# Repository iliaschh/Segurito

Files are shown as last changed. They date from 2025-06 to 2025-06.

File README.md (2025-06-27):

# Segurito 

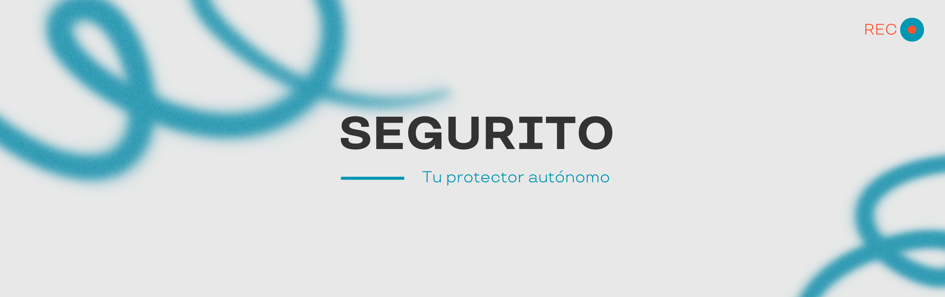
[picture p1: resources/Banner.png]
Logo del Proyecto


## Tabla de Contenidos

1. [Introducción](#introducción)
2. [Componentes y Costos](#componentes-y-costos)
3. [Características](#características)
4. [Modelo 3D](#modelo-3d)
5. [Diagramas de Arquitectura](#diagramas-de-arquitectura)
   - [Diagrama de Hardware](#diagrama-de-hardware)
   - [Diagrama de Software](#diagrama-de-software)
6. [Instalación](#instalación)
   - [Requisitos](#requisitos)
   - [Guía de Instalación](#guía-de-instalación)
7. [Uso](#uso)
   - [Escaneo y Mapeo LiDAR](#escaneo-y-mapeo-lidar)
   - [Detección de Movimiento](#detección-de-movimiento)
   - [Reconocimiento de Objetos y Rostros](#reconocimiento-de-objetos-y-rostros)
   - [Monitoreo Remoto](#monitoreo-remoto)
8. [Algoritmos](#algoritmos)
9. [Video funcionamiento](#Video-funcionamiento)
10. [Contribuidores](#contribuidores)
11. [Licencia](#licencia)

---

## Introducción

Segurito es un robot de seguridad autónomo diseñado para patrullar y supervisar espacios como lo haría un vigilante dedicado. Equipado con sensores avanzados y conectividad en la nube, Segurito:

- Mapea su entorno usando algoritmos LiDAR y SLAM
- Detecta obstáculos y objetos en movimiento para una navegación segura
- Identifica humanos y animales mediante reconocimiento por cámara
- Activa alarmas y envía notificaciones remotas al detectar intrusos
- Envia y recibe audios de voz en remoto a traves del altavoz y del micrófono integrado

Segurito combina hardware con módulos de software inteligentes para dar una solución de seguridad integral.

---

## Características

- **Mapeo Autónomo**: Genera un mapa en tiempo real del entorno usando LiDAR y SLAM.
- **Evitación de Colisiones**: Detecta y evita obstáculos.
- **Detección de Movimiento**: Sensor PIR para mayor precisión.
- **Reconocimiento de Humanos y Animales**: Clasifica las figuras capturadas por la cámara.
- **Sistema de Alarma**: Emite sonidos a traves del altavoz al detectar intrusos y enviar notificaciones.
- **Comandos de Voz**: Micrófono para hablar.
- **Conectividad en la Nube**: Envía alertas y transmisión de video en vivo a un panel remoto.

---

## Componentes y Costos

| Componente | Cantidad | Costo Aprox. (USD) | Enlace al Proveedor |
|---|:---:|---:|---|
| Micro Metal Motors | 2 | 35.00  | [Enlace](https://tienda.bricogeek.com/motores/113-motor-micro-metal-lp-con-reductora-10-1.html) |
| Raspberry Pi 4B (4 GB RAM)  | 1 | 67.90  | [Enlace](https://tienda.bricogeek.com/placas-raspberry-pi/1330-raspberry-pi-4-model-b-4-gb.html) |
| Sensor de Movimiento PIR | 1 | 1.85 | [Enlace](https://tienda.bricogeek.com/sensores-distancia/1270-modulo-sensor-pir-hc-sr501.html) |
| RPLIDAR-C1 | 1 | 79.95  | [Enlace](https://tienda.bricogeek.com/sensores-distancia/1943-rplidar-c1-360-grados-12-metros-ip54.html) |
| Acelerometro y Giroscopio | 1 | 2.95 | [Enlace](https://tienda.bricogeek.com/acelerometros/1682-modulo-gy-521-acelerometro-y-giroscopio-mpu-6050.html) |
| Ruedas Solarbotic | 2 | 9.80 | [Enlace](https://tienda.bricogeek.com/ruedas-robotica/1008-rueda-solarbotics-rw2i.html) |
| Rueda Loca | 1 | 5.50 | [Enlace](https://tienda.bricogeek.com/robotica/995-rueda-loca-plastico-abs-34.html) |
| Altavoz | 1 | 5.50 | [Enlace](https://tienda.bricogeek.com/varios/938-altavoz-con-caja-3w.html) |
| Controladores de Motor | 1 | 5.95 | [Enlace](https://tienda.bricogeek.com/controladores-motores/999-controlador-de-motores-tb6612fng.html) |
| Microfono | 1 | 7.30 | [Enlace](https://tienda.bricogeek.com/sensores-sonido/1475-microfono-digital-mems-i2s-sph0645.html) |
| Controladora de Microfono | 1 | 6.50 | [Enlace](https://tienda.bricogeek.com/arduino-compatibles/1274-nodemcu-esp32-wroom-wifi-bluetooth.html) |
| Camara | 1 | 19.95  | [Enlace](https://tienda.bricogeek.com/accesorios-raspberry-pi/822-camara-raspberry-pi-v2-8-megapixels.html) |
| Encoders de Motor | 2 | 8.50 | [Enlace](https://tienda.bricogeek.com/accesorios-motores/932-encoders-para-motores-micro-metal-12cpr.html) |
| Powerbank y Bateria | 2 | 10.00  | — |
| Breadboard y Cables | 1 | 0.00 | — |
| Chasis Impreso en 3D | 1 | 4.00 | — |
| **Total** | | **270.60**| |

---

## Modelo 3D

El chasis completo del robot y los soportes de los componentes han sido diseñados en OnShape. Puedes encontrar los archivos del modelo aquí:

- `3Dmodels/Base.stl`
- `3Dmodels/Adaptador Base.stl`
- `3Dmodels/Segundo Piso.stl`
- `3Dmodels/Adaptador Sensor PIR.stl`
- `3Dmodels/Adaptador Lidar.stl`
- `3Dmodels/Cupula.stl`

Vista Previa del Ensamblaje 3D

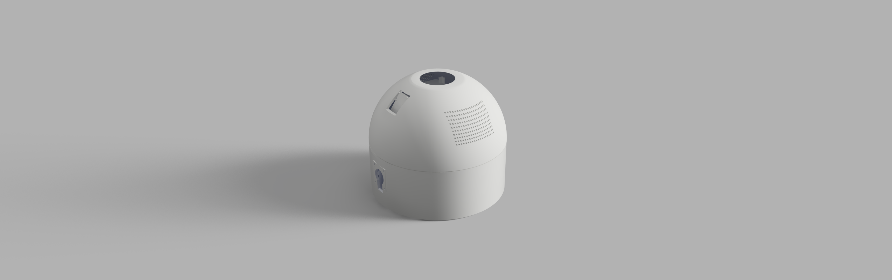
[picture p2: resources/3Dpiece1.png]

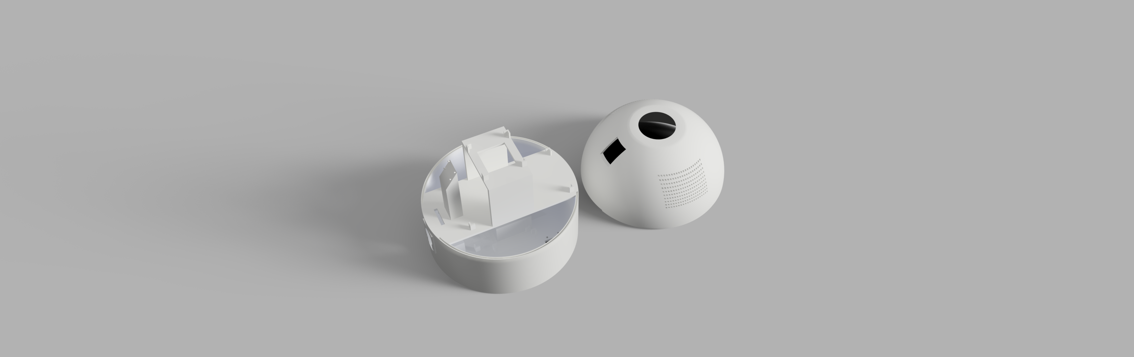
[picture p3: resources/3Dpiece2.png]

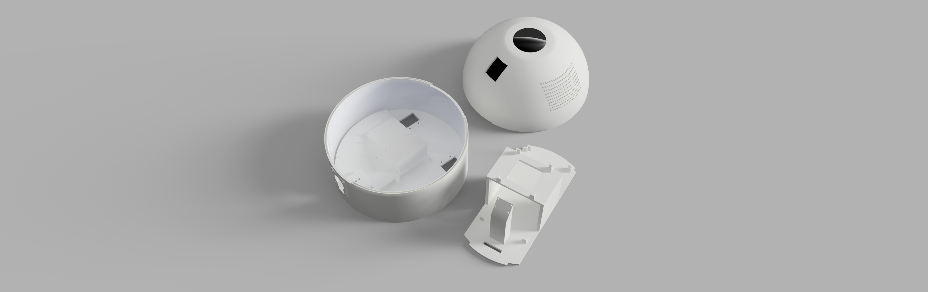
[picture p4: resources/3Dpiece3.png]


---

## Diagramas de Arquitectura

### Diagrama de Hardware

El circuito ha sido creado mediante la herramienta Fritzing, puedes encontrar el archivo aquí:

- `circuits/EsquemaCircuitos.fzz`

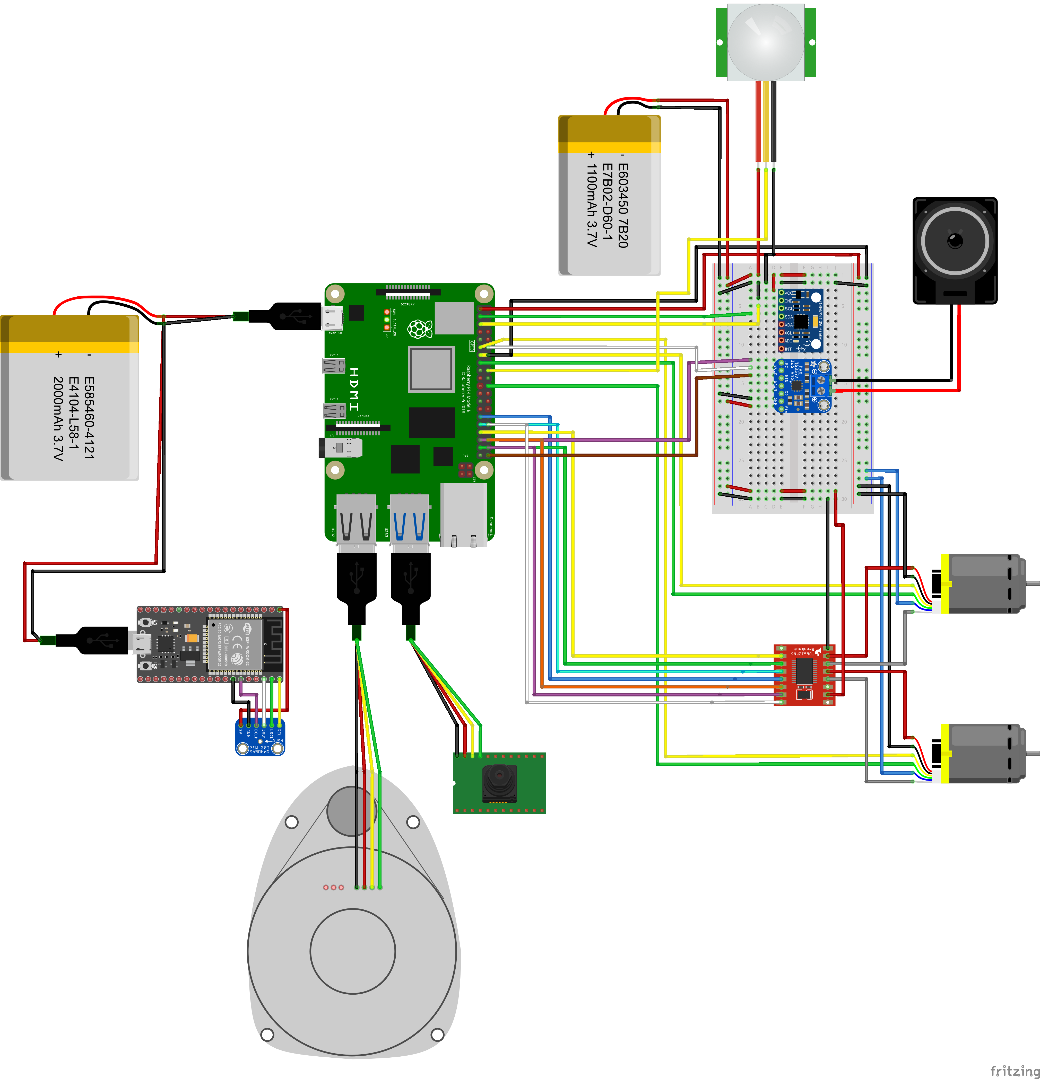
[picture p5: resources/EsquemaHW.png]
Diagrama de Hardware


### Diagrama de Software

Diagrama simplificado.

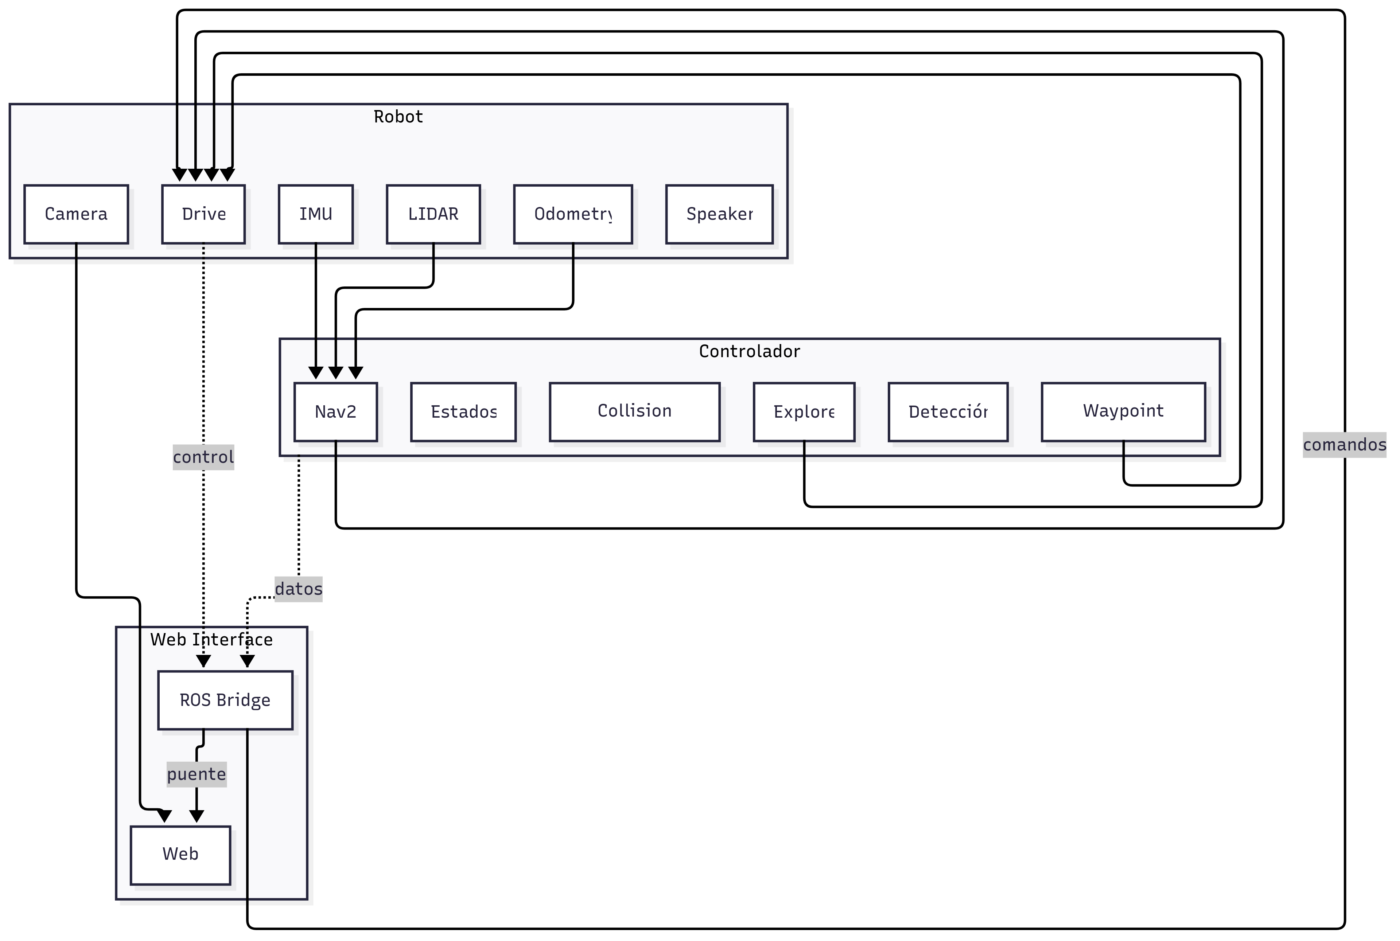
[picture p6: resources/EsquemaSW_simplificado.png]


Diagrama completo.

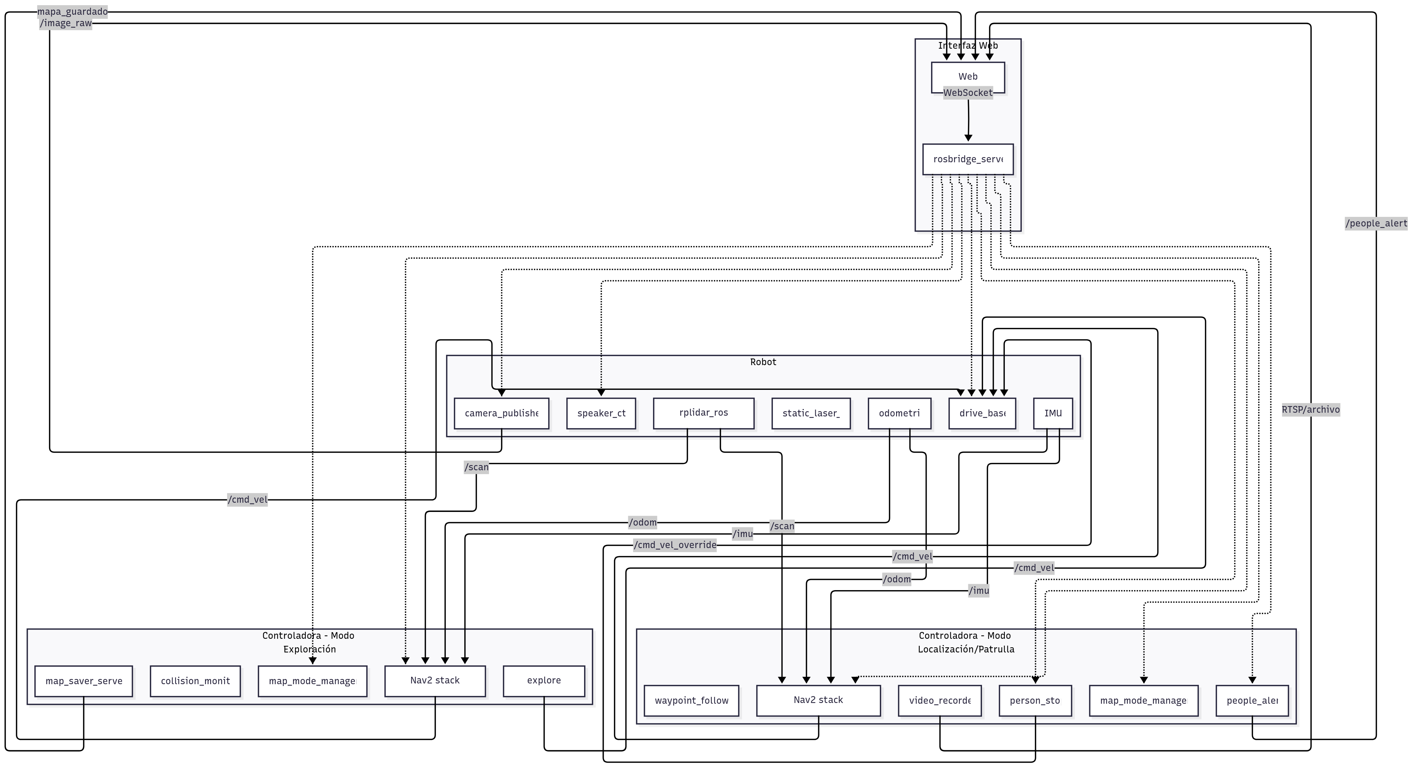
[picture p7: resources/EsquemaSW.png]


---

## Instalación

### Requisitos

| Paquete / Stack | Versión recomendada |
|---|---|
| Python | 3.10 + |
| OpenCV | 4.x |
| **ROS 2 Humble** | Desktop-Full |
| NumPy, SciPy, scikit-learn | — |
| SLAM | versión Humble |
| TensorFlow / PyTorch | — |
| **Navigation2 (stack Nav2)**<br/>`nav2_bringup`, `nav2_waypoint_follower`, `nav2_collision_monitor`, `nav2_wfd` | versión Humble |
| `rosbridge_suite` (`rosbridge_server`) | versión Humble |
| `vision_opencv` (`cv_bridge`, `image_transport`) | versión Humble |
| `rplidar_ros` | versión Humble |
| GStreamer 1.0 (para RTSP/streaming) | ≥ 1.18 |
| Node.js + npm (para la web React) | ≥ 18 LTS |

> **Nota:** ROS 2 Humble está pensado para Ubuntu 22.04 LTS.
### Guía de Instalación

> Estas instrucciones están pensadas para una **Raspberry Pi 4 B** (4 GB RAM) corriendo **Ubuntu 22.04 LTS (64 bit)**, que es la distribución soportada oficialmente por **ROS 2 Humble** y los paquetes listados en la tabla de requisitos.  
> Ajusta los comandos a tu arquitectura (x86_64 / ARM64) si vas a montar Segurito sobre otro hardware.

---

### 1. Preparar el sistema operativo

1. **Flashear Ubuntu Server 22.04 LTS**  
   Descarga la imagen para Raspberry Pi desde la web de Canonical y grábala en la micro-SD:
   ```bash
   sudo dd if=ubuntu-22.04-preinstalled-server-arm64+raspi.img \
           of=/dev/sdX bs=4M status=progress conv=fsync
   ```
2. **Primer arranque y configuración básica**  
   - Cambia la contraseña por defecto (`ubuntu/ubuntu`).  
   - Actualiza el sistema:
     ```bash
     sudo apt update && sudo apt full-upgrade -y
     sudo reboot
     ```
   - Activa la cámara y el I²C en `/boot/firmware/config.txt` (si es necesario).

---

### 2. Instalar ROS 2 Humble

> Sigue la guía oficial <https://docs.ros.org/en/humble/Installation/Ubuntu-Install-Debians.html>.

```bash
# Añadir repositorio y claves
sudo apt install curl gnupg lsb-release -y
sudo curl -sSL https://raw.githubusercontent.com/ros/rosdistro/master/ros.asc \
     | sudo tee /usr/share/keyrings/ros-archive-keyring.gpg >/dev/null
echo "deb [arch=$(dpkg --print-architecture) signed-by=/usr/share/keyrings/ros-archive-keyring.gpg] \
     http://packages.ros.org/ros2/ubuntu $(lsb_release -cs) main" \
     | sudo tee /etc/apt/sources.list.d/ros2.list

# Instalar metapaquete Desktop-Full (incluye Nav2 y rqt)
sudo apt update
sudo apt install ros-humble-desktop-full -y

# Configurar el entorno
echo "source /opt/ros/humble/setup.bash" >> ~/.bashrc
source ~/.bashrc
```

---

### 3. Instalar dependencias específicas

```bash
# LiDAR RPLIDAR-C1
sudo apt install ros-humble-rplidar-ros -y

# SLAM y exploración
sudo apt install ros-humble-rtabmap-ros ros-humble-nav2-bringup \
                 ros-humble-nav2-waypoint-follower \
                 ros-humble-nav2-collision-monitor \
                 ros-humble-nav2-wfd -y

# Puente WebSocket
sudo apt install ros-humble-rosbridge-suite -y

# Visión por computador
sudo apt install ros-humble-vision-opencv ros-humble-cv-bridge \
                 ros-humble-image-transport -y

# Python scientific stack
sudo apt install python3-pip python3-venv -y
python3 -m venv ~/segurito_venv
source ~/segurito_venv/bin/activate
pip install --upgrade pip
pip install opencv-python==4.* numpy scipy scikit-learn \
            torch torchvision tensorflow  # opcional según modelo

# GStreamer 1.18 + para streaming RTSP
sudo apt install gstreamer1.0-tools gstreamer1.0-plugins-base \
                 gstreamer1.0-plugins-good gstreamer1.0-plugins-bad -y

# Node.js 18 LTS para el panel web
curl -fsSL https://deb.nodesource.com/setup_18.x | sudo -E bash -
sudo apt install -y nodejs
```

---

### 4. Clonar y compilar el workspace

```bash
mkdir -p ~/segurito_ws/src
cd ~/segurito_ws/src
git clone https://github.com/yourusername/segurito.git
cd ~/segurito_ws

# Instalar dependencias ROS declaradas en package.xml
rosdep update
rosdep install --from-paths src --ignore-src -r -y

# Compilar con colcon
colcon build --symlink-install
source install/setup.bash
echo "source ~/segurito_ws/install/setup.bash" >> ~/.bashrc
```

---

### 5. Lanzar Segurito

```bash
# Lanza todo el stack (navegación, LiDAR, visión y web)
# Controlador
ros2 launch segurito_exploration_node web_backend.launch.py
npm dev run #Web
# Robot
ros2 launch segurito_production mapping_launch.py
```

---

### 6. Verificación rápida

| Función | Comando de prueba | Resultado esperado |
|---|---|---|
| LiDAR /scan | `ros2 topic echo /scan --once` | Muestra 360 rays JSON |
| Stream cámara | `rqt_image_view /camera/image_raw` | Imagen en vivo |
| SLAM | `ros2 launch rp_lidar_ros rp_lidar_c1.launch.py rviz:=true` | Mapa en RViz |
| Nav2 Waypoint Follower | `ros2 action send_goal /follow_waypoints nav2_msgs/FollowWaypoints`| Robot navega por los waypoints |

---

## Uso

   Una vez completada la [instalación](#instalación) y con **Segurito** encendido

### 1. Panel Web (GUI)

El panel se ejecuta automáticamente cuando lanzas el stack y está disponible en:

```
http://<IP_DEL_CONTROLADOR>:8080
```

| Función | Dónde encontrarla | Qué hace |
|---|---|---|
| **Live View** | Pestaña *Dashboard* | Muestra vídeo en tiempo real con superposición de detección de personas/animales (YOLO v11). |
| **Comenzar exploración** | Botón en *Navigation* | Inicia mapeo autónomo y exploración de fronteras usando LiDAR + SLAM *(WFD + RTAB‑Map)*. |
| **Cargar mapa** | *Maps › Upload* | Sube un `.pgm/.yaml` previamente guardado para patrullar sobre un entorno conocido. |
| **Control remoto** | Joystick virtual / teclado WASD | Teleoperación directa para movimientos puntuales. |
| **Alerts**

### Flujo típico de trabajo

1. **Lanzar stack**  
   ```bash
   ros2 launch segurito bringup.launch.py
   ```
2. Abrir navegador en `http://<IP_DEL_ROBOT>:8080`.
3. Pulsar **Empezar exploración** → el robot mapea.
4. Opcional: **Guardar mapa** al terminar.
5. En **Cargar mapa**, cargar el mapa y definir ruta de patrulla.
6. **Alerts** para recibir notificaciones fuera de horario.

Con esto, Segurito patrullará su entorno, evitará colisiones, detectará intrusos y te avisará en tiempo real.

## Algoritmos

- **SLAM**: Puntos LiDAR y odometría.

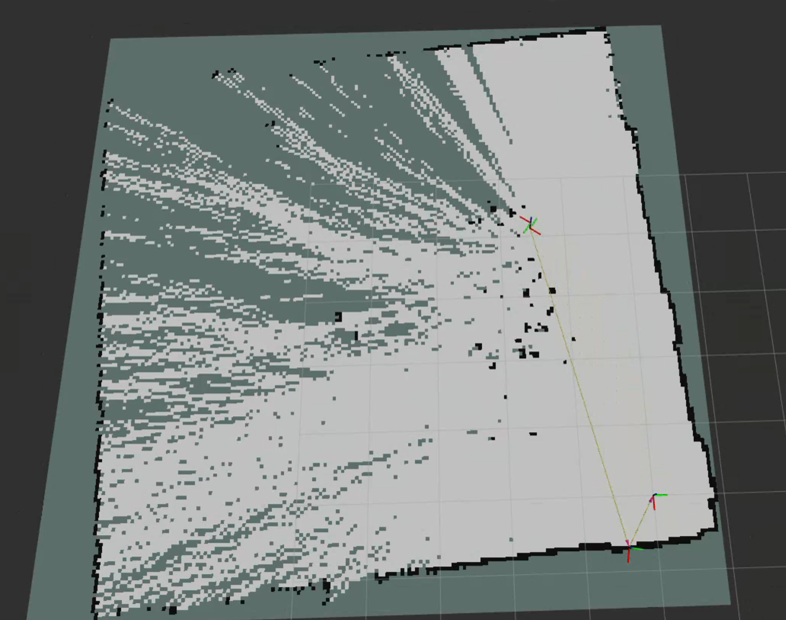
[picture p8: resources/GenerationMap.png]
Vista Previa Generation Map
   

   [Image Source](resources/GenerationMap.png)

- **Wavefront Frontier Exploration**: Método para identificar "fronteras" entre areas en un mapa de ocupación y decidir el siguiente camino.

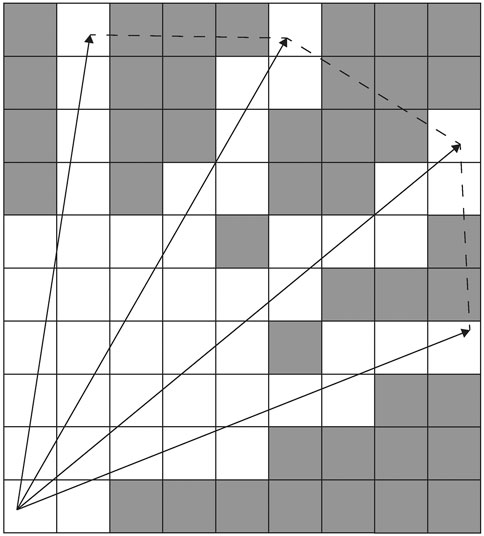
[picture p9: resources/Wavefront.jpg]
Vista Previa Wavefront
   

   [Image Source](https://www.frontiersin.org/journals/robotics-and-ai/articles/10.3389/frobt.2021.616470/full)

- **Planificación de Rutas**: Usamos A* / Dijkstra para la busqueda de la ruta optima mediante costes acumulados desde el inivio g().

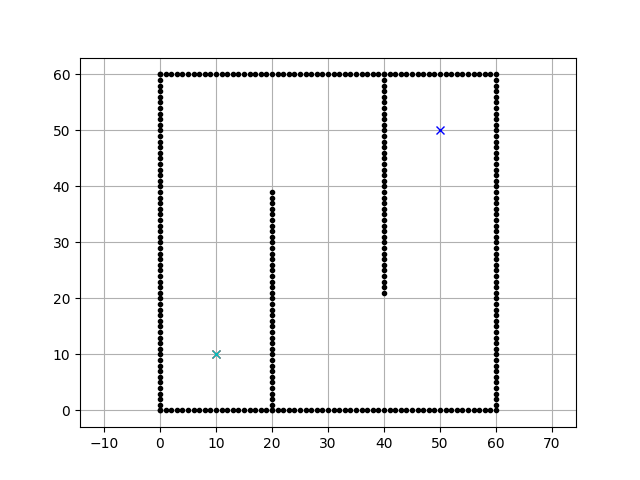
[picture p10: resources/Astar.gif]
Vista Previa A*
   

   [Image Source](https://github.com/AtsushiSakai/PythonRobotics)

- **Yolo V11**: Detector de figuras humanas de una sola etapa en tiempo real que divide la imagen en celdas para predecir simultáneamente cajas delimitadoras y probabilidades.

   Vista Previa Yolov11

   [Image Source](https://learnopencv.com/yolo11/)

---

## Video funcionamiento

Para visualizar el funcionamiento del robto puede acceder al siguiente link de youtube:

[Youtube](https://youtu.be/RQerVg_xf7g)

---

## Contribuidores

- 1 (@iliaschh) - Ilias Chakrane Hedioued   
- 2 (@isma-fernandez) — Ismael Fernandez Zarza  
- 3 (@towni848) — Antonio Morcillo Luque
---

## Licencia
MIT

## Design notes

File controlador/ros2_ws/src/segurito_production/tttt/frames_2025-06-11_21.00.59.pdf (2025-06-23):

view_frames Result

Recorded at time: 1749668459.649343

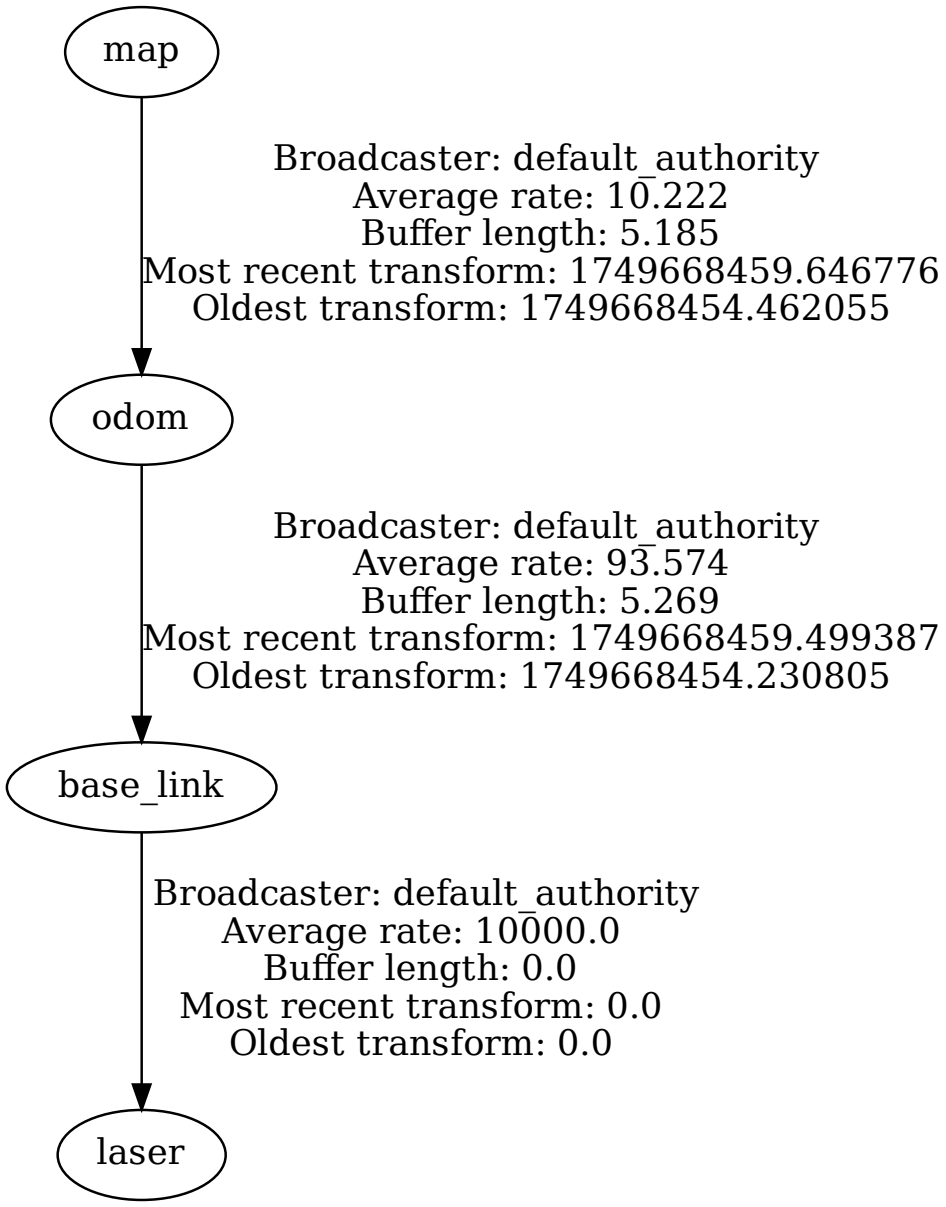
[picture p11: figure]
odom; base_link; Broadcaster: default_authority Average rate: 93.574 Buffer length: 5.269 Most recent transform: 1749668459.499387 Oldest transform: 1749668454.230805; laser; Broadcaster: default_authority Average rate: 10000.0 Buffer length: 0.0 Most recent transform: 0.0 Oldest transform: 0.0; map; Broadcaster: default_authority Average rate: 10.222 Buffer length: 5.185 Most recent transform: 1749668459.646776 Oldest transform: 1749668454.462055

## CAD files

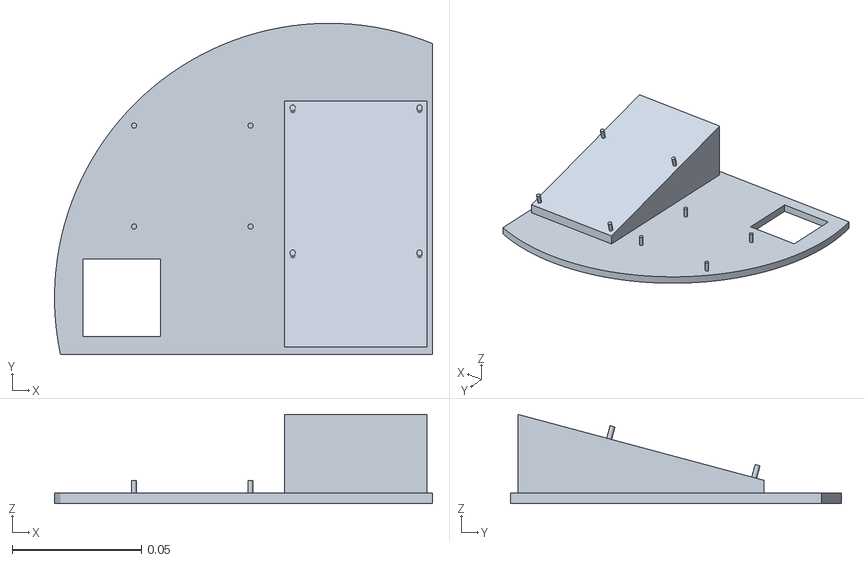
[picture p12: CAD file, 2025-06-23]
3Dmodels/Adaptador Base.stl
0.146 x 0.128 x 0.0345

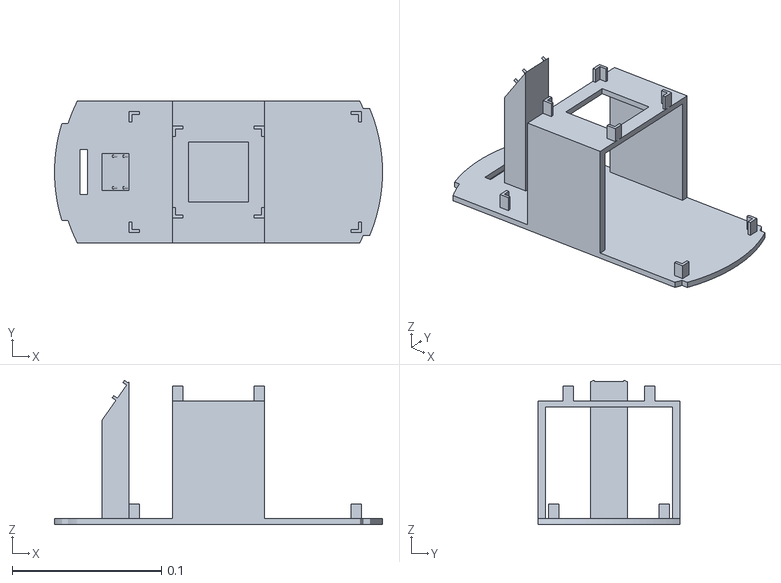
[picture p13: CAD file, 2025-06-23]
3Dmodels/Segundo Piso.stl
0.22 x 0.095 x 0.0968

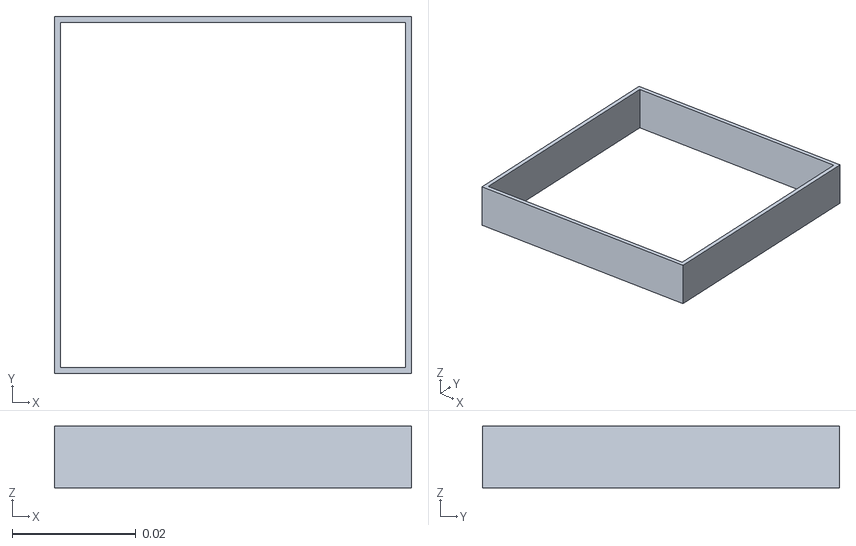
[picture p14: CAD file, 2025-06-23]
3Dmodels/Adaptador Lidar.stl
0.0576 x 0.0576 x 0.01

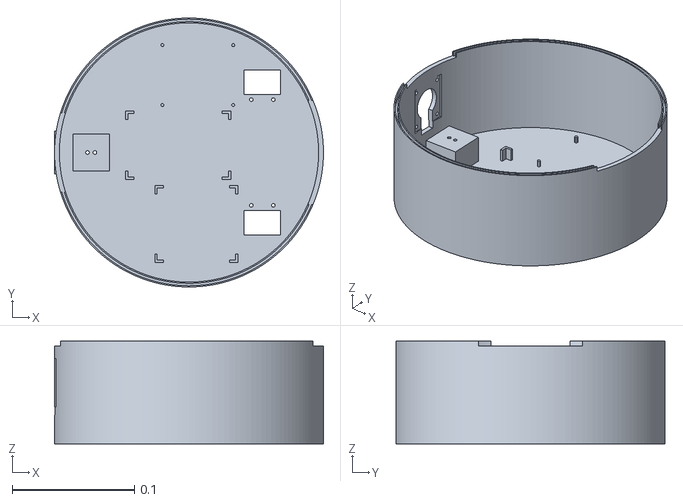
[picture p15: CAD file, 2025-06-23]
3Dmodels/Base.stl
0.22 x 0.22 x 0.084

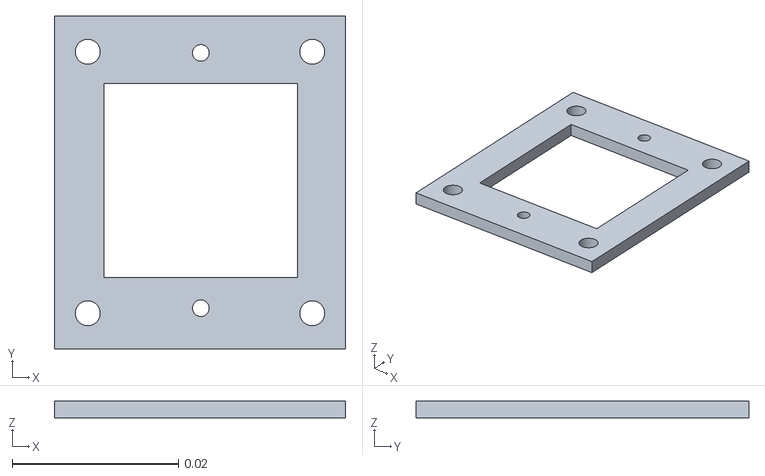
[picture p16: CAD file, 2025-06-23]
3Dmodels/Adaptador Sensor PIR.stl
0.035 x 0.04 x 0.002

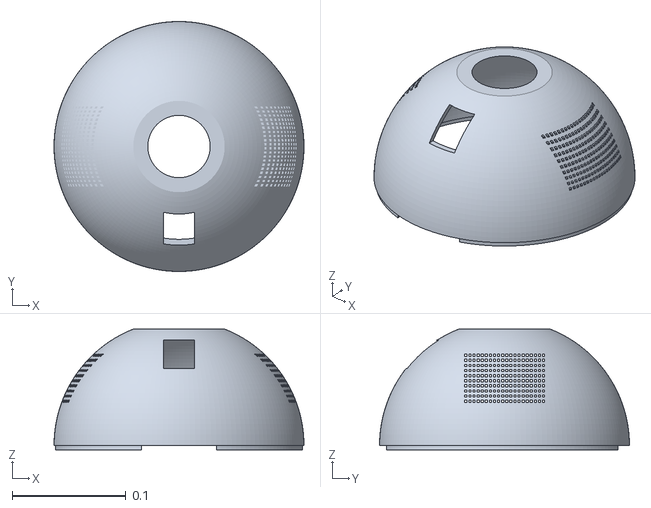
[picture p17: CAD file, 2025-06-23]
3Dmodels/Cupula.stl
0.22 x 0.22 x 0.106

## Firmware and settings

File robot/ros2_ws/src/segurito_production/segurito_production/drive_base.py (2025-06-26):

#!/usr/bin/env python3
# ─────────────────────────────────────────────────────────────────────────────
# drive_base.py  —  ROS 2 Humble
# Escucha /cmd_vel y gobierna un puente TB6612FNG por GPIO.
# Incluye "trim" por rueda para compensar motores desiguales.
# ─────────────────────────────────────────────────────────────────────────────

import rclpy
from rclpy.node import Node
from geometry_msgs.msg import Twist
import RPi.GPIO as GPIO

class DiffDriveGPIO(Node):
    def __init__(self):
        super().__init__("diff_drive_gpio")
        self.declare_parameter("wheel_radius",   0.0155)  
        self.declare_parameter("track_width",    0.108)   
        self.declare_parameter("pwm_frequency",  1000)     
        self.declare_parameter("max_speed_mps",  0.25)   
        self.PWMA = 13
        self.PWMB = 12
        self.AIN1 = 6
        self.AIN2 = 26
        self.BIN1 = 16
        self.BIN2 = 20
        self.STBY = 5
        # motores descompensados
        self.declare_parameter("left_trim",  -1.00) 
        self.declare_parameter("right_trim", 1.00)
        p = self.get_parameter
        self.track     = p("track_width").value
        self.max_v     = p("max_speed_mps").value
        self.lt        = p("left_trim").value
        self.rt        = p("right_trim").value

        GPIO.setmode(GPIO.BCM)
        GPIO.setwarnings(False)
        GPIO.setup(
            [self.AIN1, self.AIN2, self.BIN1, self.BIN2, self.STBY],
            GPIO.OUT,
            initial=GPIO.LOW,
        )
        GPIO.setup([self.PWMA, self.PWMB], GPIO.OUT, initial=GPIO.LOW)
        # controlar la velocidad máxima
        self.k_pwm = 100.0 / self.max_v
        self.pwmA = GPIO.PWM(self.PWMA, p("pwm_frequency").value)
        self.pwmB = GPIO.PWM(self.PWMB, p("pwm_frequency").value)
        self.pwmA.start(0)
        self.pwmB.start(0)
        GPIO.output(self.STBY, GPIO.HIGH) 

        self.create_subscription(Twist, "cmd_vel", self.cmd_event, 10)

        self.get_logger().info(
            "Diff-drive listo."
        )

    def cmd_event(self, msg: Twist):
        v  = msg.linear.x
        w  = msg.angular.z
        v_l = v - (w * self.track / 2.0)
        v_r = v + (w * self.track / 2.0)

        pwm_l = self.lt * max(min(v_l * self.k_pwm, 100.0), -100.0)
        pwm_r = self.rt * max(min(v_r * self.k_pwm, 100.0), -100.0)
        print("PWM A: ", pwm_l)
        print("PWM B: ", pwm_r)
        self.set_motor(self.AIN1, self.AIN2, self.pwmA, pwm_l)
        self.set_motor(self.BIN1, self.BIN2, self.pwmB, pwm_r)

    @staticmethod
    def set_motor(in1, in2, pwm, value):
        GPIO.output(in1, value > 0)
        GPIO.output(in2, value < 0)
        pwm.ChangeDutyCycle(abs(value))

    def destroy_node(self):
        self.set_motor(self.AIN1, self.AIN2, self.pwmA, 0)
        self.set_motor(self.BIN1, self.BIN2, self.pwmB, 0)
        self.pwmA.stop()
        self.pwmB.stop()
        GPIO.output(self.STBY, GPIO.LOW)
        GPIO.cleanup()
        super().destroy_node()

def main():
    rclpy.init()
    node = DiffDriveGPIO()
    try:
        rclpy.spin(node)
    finally:
        node.destroy_node()
        rclpy.shutdown()

if __name__ == "__main__":
    main()

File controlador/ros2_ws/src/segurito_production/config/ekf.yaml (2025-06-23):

ekf_filter:
  ros__parameters:
    frequency:            30.0      
    sensor_timeout:       0.5
    two_d_mode:           true

    base_link_frame:      base_link
    odom_frame:           odom
    world_frame:          odom        

    odom0:                /odom
    odom0_differential:   true       
    odom0_relative:       false
    odom0_config:         [true, true, false,
                           false, false, true,
                           true,  true,  false,
                           false, false, true,
                           false, false, false]
    imu0:                 /imu
    imu0_nodelay:         true
    imu0_differential:    false
    imu0_relative:        false
    imu0_config:          [false, false, false,
                           false, false, false,
                           false, false, false,
                           true,  true,  true,
                           true,  true,  true]
    imu0_linear_acceleration_rejection_threshold: 0.8
    imu0_angular_velocity_rejection_threshold:    0.8

    publish_tf:           true

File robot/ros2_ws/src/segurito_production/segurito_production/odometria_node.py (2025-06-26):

#!/usr/bin/env python3
import math
import threading
import time

import RPi.GPIO as GPIO     
import rclpy
from rclpy.node import Node
from nav_msgs.msg import Odometry
from geometry_msgs.msg import TransformStamped
from tf2_ros import TransformBroadcaster
from rclpy.qos import QoSProfile, DurabilityPolicy, ReliabilityPolicy


class QuadratureEncoder:
    _lookup = [0, -1, 1, 0, 1, 0, 0, -1, -1, 0, 0, 1, 0, 1, -1, 0]

    def __init__(self, pin_a: int, pin_b: int):
        self._pin_a = pin_a
        self._pin_b = pin_b
        self._ticks = 0
        self._last_state = 0
        self._lock = threading.Lock()
        GPIO.cleanup((pin_a, pin_b))
        for p in (pin_a, pin_b):
            GPIO.setup(p, GPIO.IN, pull_up_down=GPIO.PUD_UP)
            GPIO.add_event_detect(p, GPIO.BOTH, callback=self._callback)

        self._last_state = (GPIO.input(pin_a) << 1) | GPIO.input(pin_b)

    @property
    def ticks(self) -> int:
        with self._lock:
            return self._ticks

    def reset(self) -> int:
        with self._lock:
            t = self._ticks
            self._ticks = 0
            return t

    def _callback(self, channel):
        a = GPIO.input(self._pin_a)
        b = GPIO.input(self._pin_b)
        curr = (a << 1) | b
        idx = (self._last_state << 2) | curr
        delta = self._lookup[idx]
        if delta:
            with self._lock:
                self._ticks += delta
        self._last_state = curr


class OdomNode(Node):
    def __init__(self):
        super().__init__('odometria')

        GPIO.setwarnings(False)        
        GPIO.setmode(GPIO.BCM)
        
        self.R = self.declare_parameter('wheel_radius', 0.0168).value # diametro rueda   1.096 factor de correccion
        self.L = self.declare_parameter('track_width', 0.117).value  # distancia entre centros de la rueda
        self.N = self.declare_parameter('ticks_per_rev', 900).value    
        period_ms = self.declare_parameter('period_ms', 20).value
        self.publish_tf = self.declare_parameter('publish_tf', True).value
        self.dt = period_ms / 1000.0

        GPIO.setmode(GPIO.BCM)
        self.enc_left  = QuadratureEncoder(27, 22) 
        self.enc_right = QuadratureEncoder(17, 25)

        qos = QoSProfile(
                depth=10,
                durability=DurabilityPolicy.TRANSIENT_LOCAL,
                reliability=ReliabilityPolicy.RELIABLE)
        self.odom_pub = self.create_publisher(Odometry, '/odom', qos)
        self.tf_pub = TransformBroadcaster(self) if self.publish_tf else None

        # pose
        self.x = self.y = self.th = 0.0
        self.timer = self.create_timer(self.dt, self.update)

    def update(self):
        dl_ticks = self.enc_left.reset()
        dr_ticks = self.enc_right.reset()

        m_per_tick = (2 * math.pi * self.R) / self.N
        #  80 horas más tarde me arrepiento de no haber invertido los cables directamente...
        dl = dl_ticks * m_per_tick * -1 #invertir
        dr = dr_ticks * m_per_tick * -1 #invertir
        ds = 0.5 * (dl + dr)
        dth = (dl - dr) / self.L 

        if dl_ticks == dr_ticks == 0:
            # si no hay movimiento solo actualizamos el campo de tiempo
            vx = 0.0
            wz = 0.0
        else:
            self.x += ds * math.cos(self.th + 0.5 * dth)
            self.y += ds * math.sin(self.th + 0.5 * dth)
            self.th += dth
            vx = ds / self.dt
            wz = dth / self.dt

        stamp = self.get_clock().now().to_msg()
        #stamp = (self.get_clock().now() - rclpy.duration.Duration(seconds=0.05)).to_msg()
        # formato que pide ros2
        odom = Odometry()
        odom.header.stamp = stamp
        odom.header.frame_id = 'odom'
        odom.child_frame_id = 'base_link'

        odom.pose.pose.position.x = self.x
        odom.pose.pose.position.y = self.y
        odom.pose.pose.position.z = 0.0
        odom.pose.pose.orientation.z = math.sin(self.th / 2.0)
        odom.pose.pose.orientation.w = math.cos(self.th / 2.0)
        odom.twist.twist.linear.x  = vx
        odom.twist.twist.angular.z = wz
        self.odom_pub.publish(odom)

        # odom --> base_link
        if self.tf_pub:
            tf = TransformStamped()
            tf.header.stamp = stamp
            tf.header.frame_id = 'odom'
            tf.child_frame_id = 'base_link'
            tf.transform.translation.x = self.x
            tf.transform.translation.y = self.y
            tf.transform.rotation = odom.pose.pose.orientation
            self.tf_pub.sendTransform(tf)

    def destroy_node(self):
        super().destroy_node()
        GPIO.cleanup()     


def main():
    rclpy.init()
    node = OdomNode()
    try:
        rclpy.spin(node)
    except KeyboardInterrupt:
        pass
    finally:
        node.destroy_node()
        rclpy.shutdown()


if __name__ == '__main__':
    main()

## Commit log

2025-06-23 3D STL Added
    [Adaptador Base.stl, Adaptador Lidar.stl, Adaptador Sensor PIR.stl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]
2025-06-23 Fritzing circuit added
    [EsquemaCircuitos.fzz]
2025-06-23 Directory name changed
    [Adaptador Base.stl, Adaptador Lidar.stl, Adaptador Sensor PIR.stl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]
2025-06-23 Añadido código del servidor NAV2 + Explorador y código del cliente IMU - Odometria - Drive-base - Laser
2025-06-26 Finalizado traspaso de githubs, traspasada web, código nuevo y puente
